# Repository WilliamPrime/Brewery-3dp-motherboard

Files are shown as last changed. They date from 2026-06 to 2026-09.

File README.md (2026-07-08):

# Brewery-3dp-motherboard
A 3d printer expansion board designed to help with monitoring and managing thermals in a 3d printer

# Key featurs

- supports 12-30V input
-20 buffered thermistor inputs
- 12 fan outputs each with selection between 5V,12V and Vbus
- 12V is dropped down with a buck converter on the board with 12A max
  - if the input voltage is 12V the 12V buck shouldnt be used
- 5V is dropped down with a buck converter on the board with 12A max

- 4 Pwmed outputs meant for heaters or really beefy fans
- 35A max per output, 62A max across all of the ports
  - the heaters are on a seperate fuse and terminal in, allowing you to save power budget for fans or just run things at a different voltage.

So you could you could use the thermistors to do something like 

- 12 for motors
  - would allow for checking in places where you suspect hotspots, but also coldspots.
  - would montior, Extruder, Z, and then 4 motor for an AWD gantry
- temp of outside of pannels
- ambient air temp
- electronics enclosure air temp
- lower printer air temp
- mid printer air temp
- upper printer air temp
- bed edge temp 
- frame temp

# KiCAD photos



# Firmware

This board uses an STM32F407ZGT6 MCU, which is supported by mainline klipper and marlin.

# BOM

| Part | Item cost | shipping+tax cost | Total cost for item(s) | Notes |
|---|---|---|---|---|
| LCSC components | $157.72 | $39.63 | $190.90 | ordering enough to populate the 5PCBs |
| JLC PCB + stencil | $92.09 | $48.06 | $140.15 | No PCBA, im handsoldering, the boards |
| | | | | |

Total cost $331.05

There is a detailed break down of the parts to be ordered on LCSC [**here**](https://github.com/WilliamPrime/Brewery-3dp-motherboard/blob/main/PROD/Brewery_Alpha_0.01_LCSC%20bom.csv)

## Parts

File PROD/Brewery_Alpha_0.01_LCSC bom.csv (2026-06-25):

Designator | Footprint | Quantity | Value | LCSC Part #
C10, C3, C52_2, C6, C7, C72, C73, C74, C75, C76, C77, C78, C79, C8, C80, C81, C82, C83, C84, C85, C86, C87, C9 | 603 | 23 | 4.7uF | C162274
C11, C12 | 1210 | 2 | 4.7uF | C650971
C13, C14 | 1206 | 2 | 470nF | C5448902
C15, C16, C26, C39, C44, C53, C54, C55, C56, C57, C58, C59, C60, C61, C66, C67, C68, C69, C70, C71 | 402 | 20 | 100nF | C17702730
C17, C45 | 402 | 2 | 1uF | C48986272
C18, C19 | 402 | 2 | 56nF | C48642889
C2, C22, C23, C4 | C_Radial_D6.3mm_H7.0mm_P2.50mm | 4 | 47uF | C42371892
C20, C21 | 1206 | 2 | 2.2uF | C170101
C24, C5 | 1210 | 2 | 10uF | C2178567
C27, C28 | 603 | 2 | 100nF | C149620
C29 | 603 | 1 | 6.8pF | C376800
C30 | 402 | 1 | 6.8pF | C880645
C31, C32 | 402 | 2 | 8.2nF | C49451355
C33, C34 | 402 | 2 | 1nF | C301925
C35 | 805 | 1 | 47uF | C386022
C40, C41 | 402 | 2 | 390pF | C49451349
C42, C43 | 1210 | 2 | 22uF | C2918488
C46, C47 | 603 | 2 | 2.2uF | C7432779
C52 | 603 | 1 | 4.7uF | C48579647
D1, D2, D21, D22, D23, D24, D25, D26, D27, D28, D29, D3, D30, D31, D32, D33, D34, D35, D36, D37, D38, D39, D4, D40, D41, D42, D43, D44, D45, D46, D47, D48, D49, D50, D51, D52 | D_SOD-323 | 36 | D55V0M1B2WS-7 | C20615816
F1, F4 | Untitled | 2 | Fuse | C5249802
F2, F3 | XF-509P | 2 | Fuse | C41371872
J11 | USB_C_Receptacle_Amphenol_124019772112A | 1 | USB_C_Receptacle_USB2.0_14P | C2927038
J2, J29, J3, J31, J33, J35, J37, J39, J4, J41, J43, J45, J47, J49, J5, J51, J52, J53, J54, J55, J56, J57, J58, J59, J60, J61, J62, J63, J64, J65, J66, J67 | JST_XH_B2B-XH-A_1x02_P2.50mm_Vertical | 32 | JST-XH | C3012114
J1,J16,J26, J27, J68, J69 | KF135T-10.16-2P | 6 | Screw_Terminal_01x02 | C475108
J28, J30, J32, J34, J36, J38, J40, J42, J44, J46, J48, J50 | PinHeader_2x03_P2.54mm_Vertical | 12 | jumpers | C42431837
J6 | PinHeader_1x03_P2.54mm_Vertical | 1 | Conn_01x03_Pin | C5383112
L1, L2, L4, L5 | IND_SRP1038A_BRN-M | 4 | 3.3uH | C3015512
L3 | 7x6.6mm-inductor-M | 1 | 2.2uH | C41415584
R1, R122, R123, R128, R129, R134, R135, R140, R141, R146, R147, R152, R153, R158, R159, R164, R165, R2, R29, R3, R4 | 1206 | 21 | 4.7k | C311962
R10, R124, R125, R126, R127, R130, R131, R132, R133, R136, R137, R138, R139, R142, R143, R144, R145, R148, R149, R15, R150, R151, R154, R155, R156, R157, R16, R160, R161, R162, R163, R166, R167, R168, R169, R17, R18, R7, R8, R9 | 402 | 40 | 1k | C54102207
R100, R102, R104, R106, R108, R110, R112, R114, R116, R118, R120, R98 | 603 | 12 | 2k | C217935
R101, R103, R105, R107, R109, R111, R113, R115, R117, R119, R121, R99 | 603 | 12 | 20k | C50397009
R11, R13 | 402 | 2 | 80.4k | C851509
R12, R14 | 402 | 2 | 8.45k | C728566
R19, R20 | 402 | 2 | 2.1ohm | C18164296
R21 | 402 | 1 | 5.76k | C49653870
R40 | 402 | 1 | 51k | C53109425
R41 | 402 | 1 | 22.1K | C852648
R42, R43 | 603 | 2 | 1.02k | C50670244
R44, R45 | 402 | 2 | 1.47k | C49654490
R46 | 402 | 1 | 1.5k | C281775
R47 | 402 | 1 | 3.4k | C852765
R5, R6 | 603 | 2 | 1ohm | C2575859
R52, R53 | 402 | 2 | 5.1k | C453708
R54 | 402 | 1 | 21k | C2998083
R55 | 402 | 1 | 18k | C49653933
R60, R61 | 402 | 2 | 130ohm | C49653526
R80, R84, R86, R88 | 402 | 5 | 2k | C54531046
R22, R23, R24, R25, R26, R27,R81, R85, R87, R89 | 402 | 11 | 20k | C55098299
R82, R83 | 603 | 2 | 43 | C3017767
R90, R91, R92, R93, R94 | Milliohm HoT-2-4.5-11-I | 5 | 0Ohm | C5357551
SW1, SW2 | CAX TS-1185-W-4P-H1.8-160 | 2 | SW_Push | C2909682
U1, U30, U31, U32, U33 | TSSOP-14_4.4x5mm_P0.65mm | 5 | MCP6004 | C42370557
U10, U16, U17, U18, U19, U20, U21, U22, U23, U24, U25, U26, U27, U28, U29, U34, U35, U7, U8, U9 | DOZ45N03T | 20 | DOZ45N03T | C49441964
U11 | SOT-23-6 | 1 | USBLC6-2SC6 | C7519
U14 | LQFP-144_20x20mm_P0.5mm | 1 | STM32F407Z_E-G_Tx | C19156
U2 | RJR0014A-MFG | 1 | LM61430AFSQRJRRQ1 | C3188037
U4, U5 | RGY0020B | 2 | LM25145RGYR | C2876740
AA | na | 12 | jumper jumpers | C5305

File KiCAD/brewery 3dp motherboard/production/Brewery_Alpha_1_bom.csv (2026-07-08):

Designator | Footprint | Quantity | Value | LCSC Part #
C10, C3, C6, C7, C72, C73, C74, C75, C76, C77, C78, C79, C8, C80, C81, C82, C83, C84, C85, C86, C87, C9 | 0603 | 22 | 4.7uF
C11, C12 | 1210 | 2 | 4.7uF
C13, C14 | 1206 | 2 | 470nF
C15, C16, C26, C39, C44, C53, C54, C55, C56, C57, C58, C59, C60, C61, C66, C67, C68, C69, C70, C71 | 0402 | 20 | 100nF
C17, C45 | 0402 | 2 | 1uF
C18, C19 | 0402 | 2 | 56nF
C2, C22, C23, C4 | C_Radial_D6.3mm_H7.0mm_P2.50mm | 4 | 47uF
C20, C21 | 1206 | 2 | 2.2uF
C24, C5 | 1210 | 2 | 10uF
C27, C28 | 0603 | 2 | 100nF
C29 | 0603 | 1 | 6.8pF
C30 | 0402 | 1 | 6.8pF
C31, C32 | 0402 | 2 | 8.2nF
C33, C34 | 0402 | 2 | 1nF
C35 | 0805 | 1 | 47uF
C40, C41 | 0402 | 2 | 390pF
C42, C43 | 1210 | 2 | 22uF
C46, C47 | 0805 | 2 | 2.2uF
C52 | 0805 | 1 | 4.7uF
D1, D2, D21, D22, D23, D24, D25, D26, D27, D28, D29, D3, D30, D31, D32, D33, D34, D35, D36, D37, D38, D39, D4, D40, D41, D42, D43, D44, D45, D46, D47, D48, D49, D50, D51, D52 | D_SOD-323 | 36 | D55V0M1B2WS-7
F1, F4 | Untitled | 2 | Fuse
F2, F3 | XF-509P | 2 | Fuse
J1 | KF135T-10.16-2P | 1 | power in
J11 | USB_C_Receptacle_Amphenol_124019772112A | 1 | USB_C_Receptacle_USB2.0_14P
J16 | KF135T-10.16-2P | 1 | heater in
J2, J29, J3, J31, J33, J35, J37, J39, J4, J41, J43, J45, J47, J49, J5, J51, J52, J53, J54, J55, J56, J57, J58, J59, J60, J61, J62, J63, J64, J65, J66, J67 | JST_XH_B2B-XH-A_1x02_P2.50mm_Vertical | 32 | JST-XH
J26, J27, J68, J69 | KF135T-10.16-2P | 4 | Screw_Terminal_01x02
J28, J30, J32, J34, J36, J38, J40, J42, J44, J46, J48, J50 | PinHeader_2x03_P2.54mm_Vertical | 12 | jumpers
J6 | PinHeader_1x03_P2.54mm_Vertical | 1 | Conn_01x03_Pin
L1, L2, L4, L5 | IND_SRP1038A_BRN-M | 4 | 3.3uH
L3 | 7x6.6mm-inductor-M | 1 | 2.2uH
R1, R122, R123, R128, R129, R134, R135, R140, R141, R146, R147, R152, R153, R158, R159, R164, R165, R2, R29, R3, R4 | 1206 | 21 | 4.7k
R10, R124, R125, R126, R127, R130, R131, R132, R133, R136, R137, R138, R139, R142, R143, R144, R145, R148, R149, R15, R150, R151, R154, R155, R156, R157, R16, R160, R161, R162, R163, R166, R167, R168, R169, R17, R18, R7, R8, R9 | 0402 | 40 | 1k
R100, R102, R104, R106, R108, R110, R112, R114, R116, R118, R120, R98 | 0603 | 12 | 2k
R101, R103, R105, R107, R109, R111, R113, R115, R117, R119, R121, R99 | 0603 | 12 | 20k
R11, R13 | 0402 | 2 | 80.4k
R12, R14 | 0402 | 2 | 8.45k
R19, R20 | 0402 | 2 | 2.1ohm
R21 | 0402 | 1 | 5.76k
R22, R23, R24, R25, R26, R27 | 0402 | 6 | 20k
R28, R30 | 1206 | 2 | 100
R40 | 0402 | 1 | 51k
R41 | 0402 | 1 | 22.1K
R42, R43 | 0603 | 2 | 1.02k
R44, R45 | 0402 | 2 | 1.47k
R46 | 0402 | 1 | 1.5k
R47 | 0402 | 1 | 3.4k
R5, R6 | 0603 | 2 | 1ohm
R52, R53 | 0402 | 2 | 5.1k
R54 | 0402 | 1 | 21k
R55 | 0402 | 1 | 18k
R60, R61 | 0402 | 2 | 130ohm
R80, R84, R86, R88 | 0402 | 4 | 100
R81, R85, R87, R89 | 0402 | 4 | 10k
R82, R83 | 0603 | 2 | 22
R90, R91, R92, R93, R94 | Milliohm HoT-2-4.5-11-I | 5 | 0Ohm
SW1, SW2 | CAX TS-1185-W-4P-H1.8-160 | 2 | SW_Push
U1, U30, U31, U32, U33 | TSSOP-14_4.4x5mm_P0.65mm | 5 | MCP6004
U10, U16, U17, U18, U19, U20, U21, U22, U23, U24, U25, U26, U27, U28, U29, U34, U35, U7, U8, U9 | DOZ45N03T | 20 | DOZ45N03T
U11 | SOT-23-6 | 1 | USBLC6-2SC6
U14 | LQFP-144_20x20mm_P0.5mm | 1 | STM32F407Z_E-G_Tx
U2 | RJR0014A-MFG | 1 | LM61430AFSQRJRRQ1
U4, U5 | RGY0020B | 2 | LM25145RGYR

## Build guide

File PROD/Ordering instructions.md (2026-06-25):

Hi, for some reason youve decided you want to order the stuff before ive tested it.

Bold.

But anyway, the PCB has been designed for the outer layers to be at least 2Oz copper, and the innner layers at least 1Oz.

Other than that, its just a 100x140mm 4 layer PCB, nothing special, should fit into basic tolerances.

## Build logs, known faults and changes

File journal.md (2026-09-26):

# Day 1 07/06/2026 1.5 hours

## So im starting this project
My first experience with modifying a klipper board was moddifying the [klipper expander by timmit99](https://github.com/timmit99/Klipper-Expander), to have bigger mosfets as I wanted to attach some chunkier fans that wanted over 4A.

which turned it from 
this


to this


Same mounting holes, mostly the same circuitry, just bigger mosfets and a type C connector instead of a micro b port.

## time to set out what i want from this

- at LEAST 20 thermistor inputs
- all thermistor input to have overvoltage protection, i dont want to accidentally kill anything with static as i dont know where users will be sticking them
- 12 fan ports with 1-2.5A 
  - all of these fan ports should have a selector to pick between 5v, 12v or 24v/Vbus
- 4 fan parts with ~5A of max current
- USB c in with ESD protection/isolation

I should probably also make a checklist of what i need to get done

- [ ] pick an MCU
- [ ] sort out OVP for the thermistors
- [ ] sort out OCP for the fans
- [ ] sort out how im doing to do selectable voltage for the fans
- [ ] pick mosfets for the fans
- [ ] bom optimisation

## picking an MCU IC
I probably want some sort of STM32 since the klipper support for those is really good,
Time to hunt in the [ST mcu portfolio](https://www.st.com/content/st_com/en/stm32-mcu-developer-zone/mcu-portfolio.html) for something that looks good.

Ive stopped hunting in ST's tool and now im hunting in LCSC, if im buying the part from LCSC, then its useful to check it there so i dont go to find it there and be dissapointed it not there yet. 

Andddd i thought id found chip that was vuagely in the right direction, and realised another constraint i needed to look out for, does klipper support the MCU ? I know i could theoretically try and implament klipper support for a random STM32 chip however i feel like that might be difficult and i dont even know where i would start, so i will leave that as a future me project!

Anyway i found the list of currently supported MCUs for klipper, yipeeeeeee!


The first MCU I picked wasnt on LCSC
The second one didnt have klipper support

My third MCU seems to be suitable, the [STM32F07ZGT6](https://www.lcsc.com/product-detail/C19156.html)

It features:
- an ARM Cortex-M4 cpu core running at 168MHz
- 82 I/Os
- an LQFP-100(14x14) package so i can actually solder it by hand
- 512KB of built in programme storage so i can have klipper on it
- usb 2.0 support
- a built in oscilator
- has klipper support

checking the data sheet, the variant i picked has 24ADC channels which surpasses the minimum number of thermistors i want.


I could pick a smaller, cheaper STM32 and then use a number of ADS1115 4 channel ADCs via I2C, as [klipper supports those](https://www.klipper3d.org/Config_Reference.html#ads1x1x), however that might add a chunk  of mess to the config, and at ~$2 per IC, its a lot more expensive per thermistor than just buying a bigger STM32

The size (20mm x 20mm) is a tad annoying, but it is what it is, im not sure how else i expect to get so many IO/s in an LQFP package without it being big, only way to make it smaller would be BGA or similar, which i dont feel like dealing with.

So currently it looks like 
- [x] pick an MCU
- [ ] sort out OVP for the thermistors
- [ ] sort out OCP for the fans
- [ ] sort out how im doing to do selectable voltage for the fans
- [ ] pick mosfets for the fans
- [ ] start on the schematic
- [ ] bom optimisation
Onto the next part! I suspect this might be a tad tricky and involve me learning a chunk of new things

spent some time learning about op amps as i kept spotting them in some thermistor circuits.

# Day 2 08/06/2026 5.7 hours

## sort out OVP for the thermistors

First solution ive found is maybe using a TSV diode to protect them, however Im not sure how well that would do, and leakage current could be a BIG issue

Ive spotted is that some other designs use OP amps to buffer their inputs , if an op amp can help reduce reading errors, im all for it.

the OPA320, OPA323 and OPA2320 


If the OPA2320 , is a dual channel version of the OPA320, why is the OPA2320 arround 25% cheaper than the OPA320? Is there something im missing? Im aware of pricing this whole time because if i need to add 20channels worth of something price is going to be important.

Im also just going through all of the ADC temperature sensors klipper supports incase one of them is a value gem compared to an STM32.
No gems, everything was quite pricey.

Anyway back to hunting for op apms and knowledge of how to implament them with OVP

Another op amp im looking at is the MCP6004 and that series

## starting on the schematic

I wanted a break from the op amp stuff, time to do something im a bit more comfortable with, schematics!



now im curious if i could do the thermistor op am circuits as a heirarchical sheet to make it a bit less messy, anyway

It also looks like the LQFP144 package i picked can pull a good ammount of power





I will probably use a pair of ideal diodes circuits to the OR the usb 5V and 12-24V input for heaters for the drop down for the STM32.
That allows to have power via USB for flashing, but also means i can have most of the power comming from the 24V PSU not the USB bus.

Nope ive decided against that, i will just add a jumper to pick between them, i dont feel like adding $2-4 of components.

trying to pick resistors for the voltage divider is suprisingly tricky


Anddd there we go high efficiency 3.3v reg, that took a while


I also found another project with similar goals 
that being [prunt3d](https://prunt3d.com/), they used an ESD diode that appears wayy smaller than the one i was going to use ,which is nice, so ill use the [D55V0M1B2WS-7](https://www.lcsc.com/product-detail/C1976275.html) instead of the [ST SMBJ48A-TR](https://www.lcsc.com/product-detail/C133659.html) i was going to use

I did a little bit more work on the 3.3V reg, I may have forgotten a cap, however I added it back in so its fine.
Ive also been picking parts for some things as I go and adding them into my cart in LCSC


Currently the schematic looks like this 

currently the checklist looks like this, same ammount of things need doing, but ive still made good progress on the supporting components.
- [x] pick an MCU
- [ ] sort out OVP for the thermistors
- [ ] sort out OCP for the fans
- [ ] sort out how im doing to do selectable voltage for the fans
- [ ] pick mosfets for the fans
- [ ] start on the schematic
- [ ] bom optimisation

## Selectable voltage for the fans

For some reason i kind of feel like doing more volage regulator stuff

, if I want 5V and 12V options for fans, I probably need to drop down the 24V to that

# Day 3 09/06/2026  3.05 hours

Im still working on the selectable fan votlage
still working on putting together a pair of buck converters so I can have a 5V and a 12V rail without needing the user to use external power supplies.



Im not using the mosfet recommened by TI since its really expensive, I found an alternative thats substantially cheaper, i do need to make my own footprint which is normally ok,
but this is REALLYY confusing me


In the end i just used coordinates to align everything


Since i picked an IC thats super versatile
my 5v converter looks like this

and my 12v like this


All that changes is two resistors comming out of FB that determine the voltage output.

Im getting reallyy confused how to get mosfets to do what i want 



I was going to have a 3 switch, dip switch ,and then use that to let the use select between 5, 12, and 24v.
and then have each switch control a mosfet

Ignore how awfully messy this is


for the 5v rail it works

but then after that

the 12v or 24v rails will start backfeeding the 5v, and causing the source to be at 12v or 24v, which is higher than the drain at 5v, so current flows

I dont know how to fix this as I have no clue what i need to do to fix it.
So i need to watch youtube video or find some way to learn about them that dont just confuse me 

# 11/06/2026 7.3 hours

## getting on with it, addressing scope creep that happened before the project started
First thing i went and did was look at overcurrent protection for the fan ports, since i have so many, it would add AT LEAST $12 IC cost alone ignoring all the extra passives.
It would also add a bunch of complexity, so i dont need it, bye bye fan  OCP, long live the 12A or 30A fuse protecting the input terminals!

originally i wanted to do the voltage switching via dip switches, jumpers can just be kind of annoying, however i couldnt figure out how to set up an ideal switch model thingy with mosfets, so there would have been all sort of backcurrent issues. So i will do it the way that ive seen other boards do it, with jumpers. Im not the biggest fan of the jumper method since at high currents im semi worried about melting things, but I guess its "fine", its still a nice feature.
How many people use their JST-XH ports at 3A anyway?

Here is one of MANY attempts to get something to work in [Faldstad](https://www.falstad.com/circuit/), they often would have weird issues like the output volage being lower than I expected, with the cause of the voltage drop really not being clear. 


Still staying on the theme of fans, I need to pick mosfets for them, I think i will use the same mosfets that i used for the buck converters, massively overspecced , I DO NOT need 45A at 30V, however they are compact and cheap at ~$0.089 per mosfet,so still a perfectly reasonable choice . Yipeee ive avoided adding another part to the BOM.

So an indiviual fan circuit looks like this,


And 12 of them like this.


I chose to rename the FanH to Heaters1-3, it just felt correct give the power the mosfets are capable off. As the mosfets are capable of 45A, there will be a fuse rated at ~30A to protect the board and terminals.


Ive also ditched overcurrent protection for the thermistors, I have added ESD protection in the form of an ESD diode, and some resistors to hopefully stop reduce how nasty any ESD getting to the op amp is.

I picked the MCP6004 as the op amp for this board, its compact , low power, cheap, and more than good enough for this application.

Thats all the thermistor stuff done!


I did also shuffle arround all of the pins the thermistors were connected to because I forgot to check the pins had an ADC attached to them.


which means our list of things to do now looks like this
- [x] pick an MCU
- [x] thermistor op amps
- [x] sort out how im doing to do selectable voltage for the fans
- [x] pick mosfets for the fans
- [x] start on the schematic
- [ ] finish off schematics
- [ ] tidy up schematics
- [ ] bom optimisation
- [ ] routing

And the overall schematic now looks like this

the "tidy up schematics" box probably makes more sense now...

# 22/06/2026 AHHH THE ROUTINGGG AND OTHER STUFF 30 hours

So Ive done a lot of stuff since the last journal , but a LOT of it was the same sort of stuff

A LOT reading data sheets like [this one 
](https://www.ti.com/lit/ds/symlink/lm25145.pdf?ts=1782024874461)
I had particular "fun" with that one trying to make sure i followed as much of the layout guideance as possible!


I had to follow the layout guide because i was doing the layout,
because i finished off virtuially all of the schematic!

Currently the board looks something like this



A lot of the routing and layout was done in smaller discrete chunks and then smooshed into the bits of the PCB layout that were allready decided, im not sure if it was the right approach.
That approach caused me to do a lot of 
- laying out and routing a block
- moving the block into place
- moving arround parts in the block to make it fit better
- moving the block into a second better place
- more moving arround parts in the block to make it fill gaps and fit better

which felt pretty inefficient, but on the other hand I dont think the whole board could have been routed at once given the shear ammount of components and design guidelines imposed

One of the big decisions I was toying with was if i should split the PCB into two PCBs.
- a pcb for the high power stuff
- a pcb for the MCU, USB in, Fan ports 

I know if I make it all one board it will be over 100x100mm which will make it far more expensive from someone like JLC PCB
If i make it two boards then I need to deal with joining them together with some sort of connector.

Ultimatly i decided to go against the split board idea simply because i didnt want to add any extra complexity.

The PCBs wont be the cheapest though since i need 2Oz surface copper weight because of the high currents.
They also look like they will be arround 100x130mm
So i recon it will be arround $80 for 5PCBs

The buck converters did take up a good 4-6 hours, I kept realising there was another thing i could do to better optimise the footprint or adhesion to the guidline

This was the first revisision


But when you have multiple of those, the shape makes fitting them in quite akward, so i moved arround the caps to make it squarer


But that still results in dead space, so i wiggled arround some passives to try and gain more room

And that worked pretty well!!!

which means our list of things to do now looks like this
- [x] pick an MCU
- [x] thermistor op amps
- [x] sort out how im doing to do selectable voltage for the fans
- [x] pick mosfets for the fans
- [x] start on the schematic
- [ ] finish off schematics
- [X] tidy up schematics
- [ ] bom optimisation
- [ ] routing

Still some routing left, 
There will be BOM optimisation to do as i keep changing 0402 to 0602s for the sake of being able to run traces under them and also sanity when soldering.
If i want a couple of neopixel ports then i will need to add them to the schematic properly

I should also add 
- [ ] A diagram with a proper diagram of the pinout
but that should wait for after ive finished the layout as current im still playing arround with how to organise things.

# 22/06/2026 the last bit of routing is proving to be a bit of a pain 5 hours


trying to route everything is just becomeing more and more of a pain because the traces often connect to the wrong side and in a place that just doesnt make sense.

I recon the soluation to this is abandoing a pin numbering scheme that makes sense, making a list of all pins with ADC and just picking ones that minimise the ammount of crossing over i need.
The crossing over is really annoying as the vias just prove to be in the way again and again.

PA0-7
PB0, PB1
PC0-5
PF3-10

are the 24 GPIO pins i can use to get an ADC connection.

Given there are 24 and I need to use 20 of them, I dont think its going to give me a ton of flexibility to stop traces needing to travel to the bottom of the chip instead of the top, but knowing which i can play with should still help in avoiding some of the crossing over.

Ive chucked a blue box next to each pin i can juggle arorund.


I will also probably do the same for the PWM outputs


I ended up getting a list of all the pins, and a list of which pins have an ADC in, and which have a PWM out.
Then taking away the ADC in from the PWM out so i dont accidentally use a pin i want.

I also removed pins where the TIM channel was used by multiple pins, leaving me with that selection of boxes

The part i have routed are much neater, there are still all of the fan PWM inputs to route, so its too early to say how its truely turned out.

I would also throw in a bit of DCR here and there to make DRC more bareable at the end.
It may be a lot of errors, but it was a lot higher :sob: 


Anyway, still lots more routing to do! 

# finishing off the PCB 23/06/2026 -6 hours

This session has been a lot of cleaning things up, such as the routing for everything connecting to the MCU

previously it looked like this
image (5)
That mess was only going to get worse, I hadnt even get routed half of the fans or any of the heaters.

With everything routed to the MCU it looks like
image (6)
which I think is a LOT cleaner

I also spent a while trying to work my way through all of the DRC issues

that is the highest number of DRC errors ive ever seen.

Some of the issues were harder to sovle and ive still not solved them, just ignored them as I think there is a good chance that its just KiCAD glitching out

such as this scenario
image (8)
image (7)
image (9)

the anular for that hole should be 0.125mm , but kicad thinks its 0.0999999 no matter what i change the diameter to.
I needed to change the anual to something larger so whatever PCB fab i pick can make it, and that still didnt fix it.
If my PCB fab can do it, then im happy, kicad can go sulk about it some more or something.

Anyway there were a LOT of DRC issues, it took a while.

My next step is going to be trying to make a bom file with all of LCSC part numbers.

#24/06/2026 AHHHH - arround 4-6 hours

most of this chunkkk of time has been spent picking components on LCSC

The bom starts out looking like that, and then I needed to find the component in the circuit and check for any special requirements

For example with the resistors used as a voltage divider for the thermistors i wanted them to be fairly accurate. 
But for some other things like where the resistors were simply there for the purpose of limmitting current I would quite happily pick +-10% if it existed and was cheaper

The caps were a bit tricker, as for some of them , picking a higher voltage rating would make them a lot pricier
for example the 1210 footprint 4.7uF caps needed for the 3.3V voltage regulator,
If you want then in 5V , they cost arround $0.05 each, but if they are exposed to the incomming 24-30V , they need to be rated to something higher like 36V
which then makes them cost $0.23 each

picking the voltage rarting for a cap was also interesting in situations like when the cap is used in a bunch of places, when it was a negligable ammount more i would go for 36V rated caps as that would be fine no matter the voltage input

There was also a bunch of noticing stuff like "uh oh, why is that 0402 cap 10uF" and then proceeding to realised that needs to be bigger to actaully have that much capacitance

or when i realised that the reistors i used to limmit the inrush current into the mosfet gates werent enough, it would cause an inrush higher than what the MCU GPIO pins were rated for.
Which once again led downa rabbit hole of changing out components, re creating the BOM and copying over the stuff that was allready done.

There were also some really annopying things i encountered, such as the voltage regulator i used for 3.3V and my chosen MCU both being out of stock on LCSC.
After some research on LCSC i found an automotive variant of the vreg that was a little more, but a pin for pin replacement.

The MCU was a bit trickier, but ultimatly i found a version with a higher temp rating , other than it was identical to the original MCU.
Well, the price was also more, but changing the MCU would require a chunk more work and re routing, and its not like I chose an MCU that is EOL, so the project should still be recreatable in the future.

That IC bom from the start now looks like this

An LCSC part num next to every component.

# Start of the build!!!

you will probably notice that the build was uploaded all in one go, thats because when I was assembling the PCB I would have my laptop next to me for KiCad etc, and as wonderful as github is, loosing your progress because you accidentally close the chrome tab before you commit the changes to the .md is reallyyyy annoying , so I journalled everything into Obsidian notes, and then copy pasted to here!

# 06/07/2026 PART ARRIVING!!! 0.5 hours

wow the terminals are big, today was spent sorting the components into piles ready for as soon as the PCBs arrive!

if you're wondering what piles i sort them into
- resistors
	- by value footprint, 
	- if multiple of same value, smallest package first
- capacitors
	- by value footprint, 
	- if multiple of same value, smallest package first
- special SMD stuff
	- stuff like op amps, micro conctrollers, mosfets etc
- through hole stuff



# 08/07/2026 PCBs ARRIVED TIME TO SOLDER!!! - 4h




I got a decent stencil application, but i think  i accidentally went over the same area twice on the right hand side of the board, so there was a lot of paste there



also made a good start onto placing components!!!



oh., and i regret using 0402, i can do it, its just that 0603 is soo muchhh easier, i can do 0603 with my fingers, 0402 and 0201 are just ,needlessly fiddly for a board like this.

# 09/07/2026 still placing new parts on - 3h
so, it says this is a new day in the journal, but urm, its past midnight!!!
since i don't want all the flux in the paste to dry up and make my life harder, I kept placing components!!
and wow there are a lot of components!



i dont know why i didnt get a photo before i reflowed
but here is a photo post reflow of me trying to cool the board!!



once your usb wires start looking like this, you know the project is going to get more intersting.



so it turned out that i picked the wrong type of USB-C connector footprint in KiCad, which made for an interesting discovery when trying to solder on the USB C port...

# 10/07/2026 USB + trying to get power on the 3v3 rail - 7 hours

I finished bodging the USB thing, so that should be sorted, not great, but okay.



have been trying to identify why im not getting 3.3v



photos of the area don't make it look awful 

ive got a janky thing instead of the jumper, i dont want to solder the through hole pins for the selection source for the 3.3v reg, as otherwise i wont get as good contact with the hotplate when reflowing, so ive done this


i still need to remove it, but its not as hard

5v looks clean ish, but im not sure whats causing that nose



and then my 3.3v rail is looking like this



its supposed to be operating at around 2.2MHz so i dont expect anything spicy at this scale, but given im at 1.12V im guessing ive either got a mistake on my resitsors, or the freq selection stuff.



and now im just getting noise

noise that keeps changing


anddd i worked out i left a pin floating that should have been grounded...



so now that's bodged with a wire under it that i can join to gnd somewhere

so much time spent trying to work out exactly whats gone wrong :sob: 

# 11/07/2026 more trying to fix the 3.3V regulator - 6 hours

I've really been having an experience trying to fix the 3.3V reg, I think the long wire i tried to use before was too long and acting as an atenna at those frequencies or just something was wrong.
Soooo here are my various attempts including
- shorter wire
- shorter wire again
- scrapping of coppuer under the footprint to try and get a bridge between the pin and the copper
- another attempt at that
- even more attempts at that
_DSC5476
_DSC5472
_DSC5475
_DSC5468
_DSC5465
_DSC5449

the 3.3V reg still doesn't work...

# 22/09/2026 soldering up another board - 3 hours 

Given how much reflowing I did on the original almost fully populated PCB, I thought to give myself the best chance of not just having random dead ICs, I should assemble a board where Ipopulate near the minimum components to test if it works properly.

_DSC6055



# 23/09/2026  placing the last parts onto the 2nd board and reflowing - 3 hours

i finally got all the parts onto the second board and reflowed all of it. Annoyingly since i waited so long the flux in the past dried out making the sticking of components down to the PCB much harder.



its not as clean as the other


but took less time to get populated as I skipped a bunch of stuff, and stuff that was harder to solder like the big inductors that sucked to get soldered.
# 24/09/2026 stm32 shaped 2.5W heater - 8 hours

today has been full of "experiences" when trying to get the PCB working

first thing i did that messed me up was soldering on a terminal 90degrees out of alignment...

Getting them to solder down was INCREDIBLY difficult , and getting one out was even harder,
When you have tons of vias, massive uninterrupted power planes, and extra thermal mass and conductivity from having of 2oz external copper, and 1oz internal copper , it make the experience even more "fun". I think it took a good 4min of dual wielding a hot air gun and a soldering iron to get it out. And "getting it out" meant getting it to drop around 2mm, so i could use side cutter to get it out because it did NOT want to come out.

here is a photo of the poor state that PCB was in :(



But in the end i got it out!!!

here is a photo of how the PCB looks now



which got me back to having a populated PCB!!

#### This is the part of todays journal where I explain the title being "stm32 shaped 2.5W heater"

So at this point I have
- a virtually fully populated PCB with a potentially heat damaged STM32
- a functionally populated board that shouldn't have any heat damaged components

So I get some things together


- multi meter because the owon P4305 has an amperage accuracy of arround +-10ma, if a healthy STM32 pulls 5-10mA, and a dead one pulls 0mA, then i cant tell the difference without the multimeter
- modern linear PSU that i trust to actually output the right voltage
	- using this for the 3.3V since ive had so many issues with it and its killed so much of my time
- 2nd PSU to do the 12-24V input

I hook everything up as you'd expect to the semi populated board as i thought id have a better chance getting something out of that one. I turn on the 3.3V psu and instantly hit the overcurrent protection, what on earth is pulling 1.5A of 3.3V?

So I grab a multimeter and measure the resistance between GND and the 3.3V rail, ~1Ohm, not normal

some extra attentive checking for shorted pads on the stm32 later and nothing looks wrong, but ive touched some pads up 
_DSC6074
_DSC6077
_DSC6076
_DSC6075

Try 2 , ***beeeep***, overcurrent protection again...
but nothing is catching fire, nothing is going bang etc, so given its a semi populated PCB, i thought id turn the overcurrent protection off, and just run up the current limit until i could feel a component getting warm. 

100mA, nothing,
200mA nothing, 
1.5A limit, YUP THE STM32 IS GETTING WARM FAST

The heat was coming from the package so i presume id probably managed to damage it with heat.

It being the fault of the STM32 was confirmed when i desoldered it an my GND-3.3V resistance dropped to 5.6kOhms

a replacement STM32 got that current down from 1.5A to ~7mA, which makes sense 

Pasted image 20260926011845

The board I thought would have issues only pulled ~5mA also in the healthy range, so hopefully i should have two boards that just need a flash then should work!

# 25/09/2026 actually getting it working and getting a demo video - 3 hours

well this makes for some fun trouble shooting


Pulls the right amount of power as if its a working stm32, but doesn't want to talk to me


Also a fun time to realize that breaking out the SWD pins is normally something that people do to help with troubleshooting.

its also certainly a setup im working with


So now i could have any of the following issues:
- issue with my pcb design (unlikely)
- issue with my USB cable "solution" (likely)
- issue with my power supply (unlikely)
- something else ??

Anddddd its communicating!!!

it fell into the  "issue with my pcb design", not as unlikely as I thought
Boot0 was properly set up with a pull down resistor and a switch to pull it up
But Boot1 was left floating, it should have been pulled down...
It was NOT broken out
soldering on the STM32s legs is trickyyyyy...



fan go spinny spinny  
*insert happy William noises*

# lessons ive learnt from this
- DOUBLE CHECK YOUR FOOTPRINTS
- THERMAL RELIFS ARE IMPORTANT TO MAKE THINGS SOLDERABLE WHEN YOUR PCB HAS 2OZ COPPER
- add holes so I can use a stand to hold the PCB
- make sure to break out the SWD pins an STM32, makes debugging easier
- be suspicious of stuff that is left floating in your schematic

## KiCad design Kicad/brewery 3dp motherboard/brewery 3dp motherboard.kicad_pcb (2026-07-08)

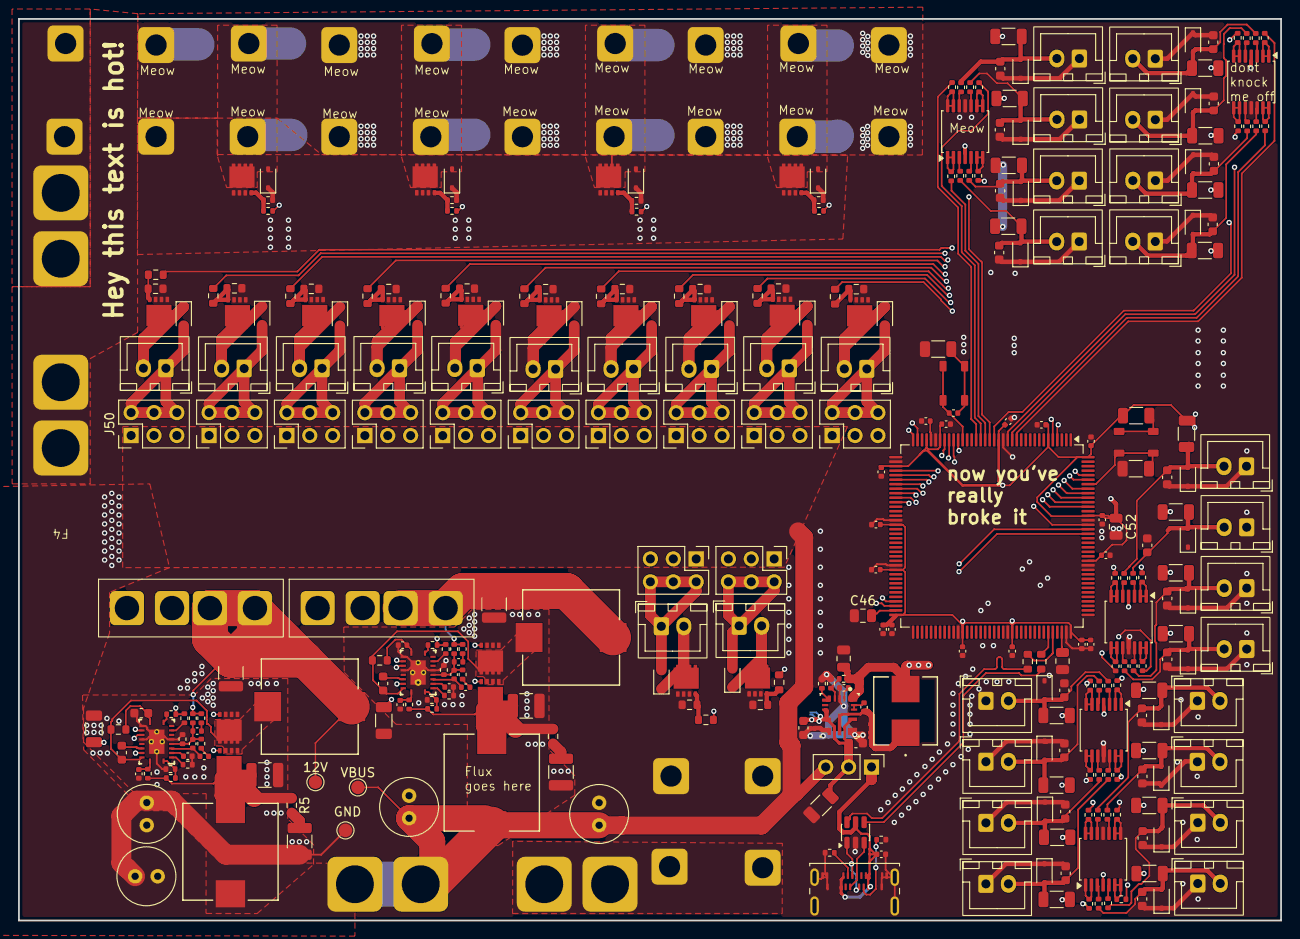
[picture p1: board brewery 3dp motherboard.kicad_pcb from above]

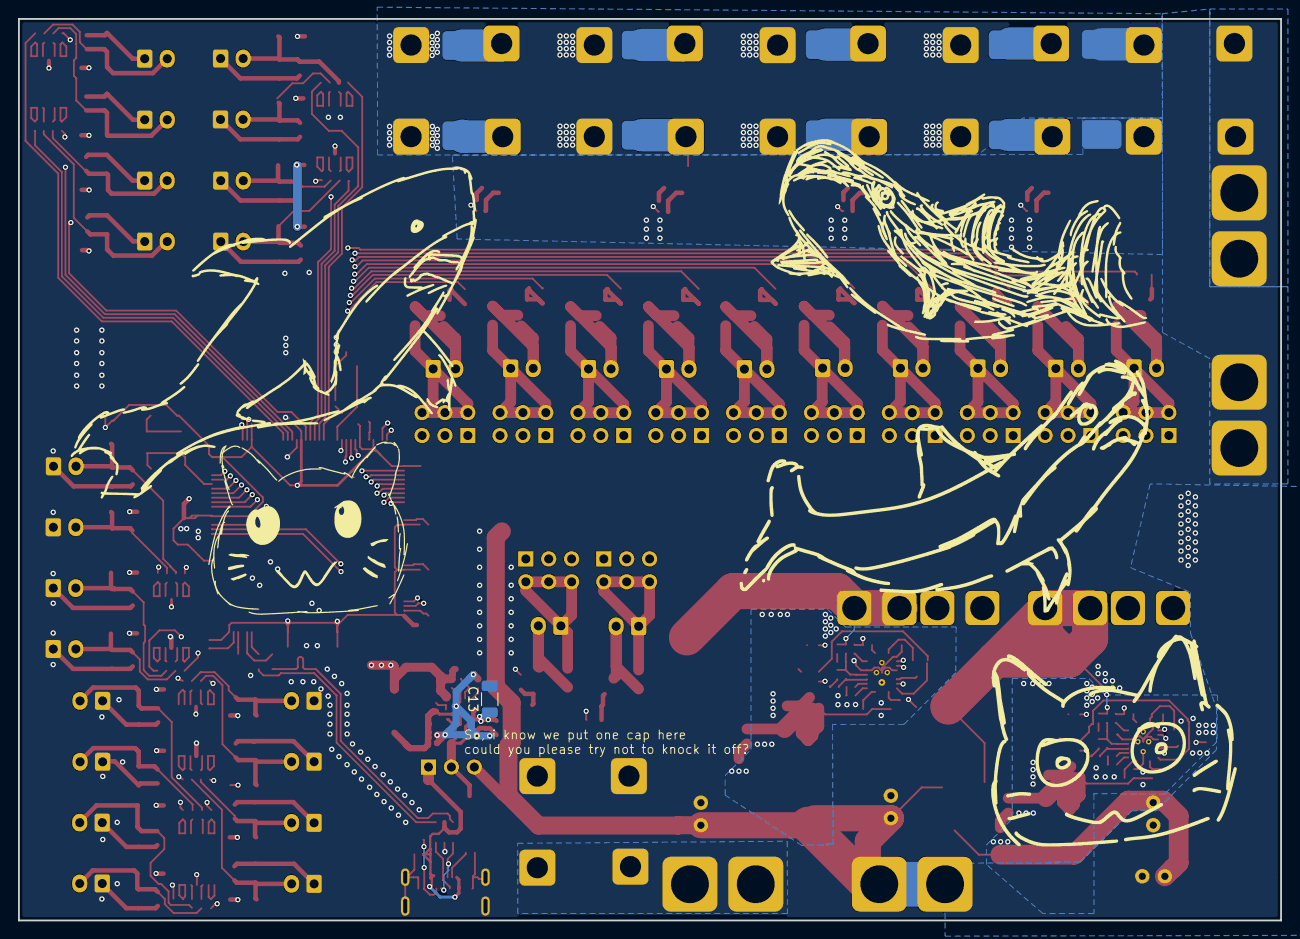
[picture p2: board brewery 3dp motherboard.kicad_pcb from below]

Board: 4 copper layers, 140.0 x 100.0 mm, 337 parts (6 on the bottom side), 208 nets.

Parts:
12V: TestPoint_Pad_D1.5mm
C2, C4, C22, C23: 47uF; C_Radial_D6.3mm_H7.0mm_P2.50mm
C3, C6, C7, C8, C9, C10, C72, C73, C74, C75, C76, C77, C78, C79, C80, C81, C82, C83, C84, C85, C86, C87: 4.7uF; C_0603_1608Metric
C5, C24: 10uF; C_1210_3225Metric
C11, C12: 4.7uF; C_1210_3225Metric
C13, C14: 470nF; C_1206_3216Metric
C15, C16, C26, C39, C44, C53, C54, C55, C56, C57, C58, C59, C60, C61, C66, C67, C68, C69, C70, C71: 100nF; C_0402_1005Metric
C17, C45: 1uF; C_0402_1005Metric
C18, C19: 56nF; C_0402_1005Metric
C20, C21: 2.2uF; C_1206_3216Metric
C27, C28: 100nF; C_0603_1608Metric
C29: 6.8pF; C_0603_1608Metric
C30: 6.8pF; C_0402_1005Metric
C31, C32: 8.2nF; C_0402_1005Metric
C33, C34: 1nF; C_0402_1005Metric
C35: 47uF; C_0805_2012Metric
C40, C41: 390pF; C_0402_1005Metric
C42, C43: 22uF; C_1210_3225Metric
C46, C47: 2.2uF; C_0805_2012Metric
C52: 4.7uF; C_0805_2012Metric
D1, D2, D3, D4, D21, D22, D23, D24, D25, D26, D27, D28, D29, D30, D31, D32, D33, D34, D35, D36, D37, D38, D39, D40, D41, D42, D43, D44, D45, D46, D47, D48, D49, D50, D51, D52: D55V0M1B2WS-7; D_SOD-323
F1, F4: Fuse; Untitled
F2, F3: Fuse; XF-509P
GND: TestPoint_Pad_D1.5mm
J1: power in; KF135T-10.16-2P
J2, J3, J4, J5, J29, J31, J33, J35, J37, J39, J41, J43, J45, J47, J49, J51, J52, J53, J54, J55, J56, J57, J58, J59, J60, J61, J62, J63, J64, J65, J66, J67: JST-XH; JST_XH_B2B-XH-A_1x02_P2.50mm_Vertical
J6: Conn_01x03_Pin; PinHeader_1x03_P2.54mm_Vertical
J11: USB_C_Receptacle_USB2.0_14P; USB_C_Receptacle_Amphenol_124019772112A
J16: heater in; KF135T-10.16-2P
J26, J27, J68, J69: Screw_Terminal_01x02; KF135T-10.16-2P
J28, J30, J32, J34, J36, J38, J40, J42, J44, J46, J48, J50: jumpers; PinHeader_2x03_P2.54mm_Vertical
L1, L2, L4, L5: 3.3uH; IND_SRP1038A_BRN-M
L3: 2.2uH; 7x6.6mm-inductor-M
R1, R2, R3, R4, R29, R122, R123, R128, R129, R134, R135, R140, R141, R146, R147, R152, R153, R158, R159, R164, R165: 4.7k; R_1206_3216Metric
R5, R6: 1ohm; R_0603_1608Metric
R7, R8, R9, R10, R15, R16, R17, R18, R124, R125, R126, R127, R130, R131, R132, R133, R136, R137, R138, R139, R142, R143, R144, R145, R148, R149, R150, R151, R154, R155, R156, R157, R160, R161, R162, R163, R166, R167, R168, R169: 1k; R_0402_1005Metric
R11, R13: 80.4k; R_0402_1005Metric
R12, R14: 8.45k; R_0402_1005Metric
R19, R20: 2.1ohm; R_0402_1005Metric
R21: 5.76k; R_0402_1005Metric
R22, R23, R24, R25, R26, R27: 20k; R_0402_1005Metric
R28, R30: 100; R_1206_3216Metric
R40: 51k; R_0402_1005Metric
R41: 22.1K; R_0402_1005Metric
R42, R43: 1.02k; R_0603_1608Metric
R44, R45: 1.47k; R_0402_1005Metric
R46: 1.5k; R_0402_1005Metric
R47: 3.4k; R_0402_1005Metric
R52, R53: 5.1k; R_0402_1005Metric
R54: 21k; R_0402_1005Metric
R55: 18k; R_0402_1005Metric
R60, R61: 130ohm; R_0402_1005Metric
R80, R84, R86, R88: 100; R_0402_1005Metric
R81, R85, R87, R89: 10k; R_0402_1005Metric
R82, R83: 22; R_0603_1608Metric
R90, R91, R92, R93, R94: 0Ohm; Milliohm HoT-2-4.5-11-I
R98, R100, R102, R104, R106, R108, R110, R112, R114, R116, R118, R120: 2k; R_0603_1608Metric
R99, R101, R103, R105, R107, R109, R111, R113, R115, R117, R119, R121: 20k; R_0603_1608Metric
SW1, SW2: SW_Push; CAX TS-1185-W-4P-H1.8-160
U1, U30, U31, U32, U33: MCP6004; TSSOP-14_4.4x5mm_P0.65mm
U2: LM61430AFSQRJRRQ1; RJR0014A-MFG
U4, U5: LM25145RGYR; RGY0020B
U7, U8, U9, U10, U16, U17, U18, U19, U20, U21, U22, U23, U24, U25, U26, U27, U28, U29, U34, U35: DOZ45N03T
U11: USBLC6-2SC6; SOT-23-6
U14: STM32F407Z_E-G_Tx; LQFP-144_20x20mm_P0.5mm
VBUS: TestPoint_Pad_D1.5mm

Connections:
+3.3V: C35.1, C52.1, C53.1, C54.1, C55.1, C56.1, C57.1, C58.1, C59.1, C60.1, C61.1, C66.1, C67.1, C68.1, C69.1, C70.1, C71.1, L3.2, R1.2, R2.2, R3.2, R4.2, R28.1, R40.2, R122.2, R123.2, R128.2, R129.2, R134.2, R135.2, R140.2, R141.2, R146.2, R147.2, R152.2, R153.2, R158.2, R159.2, R164.2, R165.2, U1.4 (V+), U2.1 (BIAS), U14.6 (VBAT), U14.17 (VDD), U14.30 (VDD), U14.33 (VDDA), U14.39 (VDD), U14.52 (VDD), U14.62 (VDD), U14.72 (VDD), U14.84 (VDD), U14.95 (VDD), U14.108 (VDD), U14.121 (VDD), U14.131 (VDD), U14.144 (VDD), U30.4 (V+), U31.4 (V+), U32.4 (V+), U33.4 (V+)
+5V: F3.1, J28.5, J30.5, J32.5, J34.5, J36.5, J38.5, J40.5, J42.5, J44.5, J46.5, J48.5, J50.5
+12V: F2.1, J28.3, J30.3, J32.3, J34.3, J36.3, J38.3, J40.3, J42.3, J44.3, J46.3, J48.3, J50.3
BOOT0: R29.2, SW2.2, U14.138 (BOOT0)
Fan1: R98.1, U14.127 (PG12)
Fan2: R106.1, U14.128 (PG13)
Fan3: R100.1, U14.129 (PG14)
Fan4: R108.1, U14.133 (PB3)
Fan5: R102.1, U14.134 (PB4)
Fan6: R110.1, U14.135 (PB5)
Fan7: R104.1, U14.136 (PB6)
Fan8: R112.1, U14.137 (PB7)
Fan9: R114.1, U14.139 (PB8)
Fan10: R118.1, U14.140 (PB9)
Fan11: R116.1, U14.5 (PE6)
Fan12: R120.1, U14.4 (PE5)
GND: C2.2, C3.2, C4.2, C5.2, C6.2, C7.2, C8.2, C9.2, C10.2, C11.2, C12.2, C13.2, C14.2, C15.2, C16.2, C17.2, C18.2, C19.2, C20.2, C21.2, C22.2, C23.2, C24.2, C29.2, C30.2, C35.2, C39.1, C42.2, C43.2, C45.1, C46.1, C47.1, C52.2, C53.2, C54.2, C55.2, C56.2, C57.2, C58.2, C59.2, C60.2, C61.2, C66.2, C67.2, C68.2, C69.2, C70.2, C71.2, C72.2, C73.2, C74.2, C75.2, C76.2, C77.2, C78.2, C79.2, C80.2, C81.2, C82.2, C83.2, C84.2, C85.2, C86.2, C87.2, D1.1 (A1), D2.1 (A1), D3.1 (A1), D4.1 (A1), D33.1 (A1), D34.1 (A1), D35.1 (A1), D36.1 (A1), D37.1 (A1), D38.1 (A1), D39.1 (A1), D40.1 (A1), D41.1 (A1), D42.1 (A1), D43.1 (A1), D44.1 (A1), D45.1 (A1), D46.1 (A1), D47.1 (A1), D48.1 (A1), D49.1 (A1), D50.1 (A1), D51.1 (A1), D52.1 (A1), GND.1, J1.1, J2.1, J3.1, J4.1, J5.1, J11.A1 (GND), J11.A12 (GND), J11.B1 (GND), J11.B12 (GND), J11.SH (SHIELD), J16.1, J52.1, J53.1, J54.1, J55.1, J56.1, J57.1, J58.1, J59.1, J60.1, J61.1, J62.1, J63.1, J64.1, J65.1, J66.1, J67.1, R12.1, R14.1, R21.2, R22.1, R23.1, R29.1, R30.1, R41.1, R46.1, R47.1, R52.2, R53.2, R81.1, R85.1, R87.1, R89.1, R94.1, R94.2, R99.1, R101.1, R103.1, R105.1, R107.1, R109.1, R111.1, R113.1, R115.1, R117.1, R119.1, R121.1, U1.11 (V-), U2.3 (AGND), U2.9 (PGND1), U2.11 (PGND2), U4.6 (AGND), U4.12 (PGND), U4.15 (EP), U4.21 (EP), U4.GND, U5.6 (AGND), U5.12 (PGND), U5.15 (EP), U5.21 (EP), U5.GND, U8.1 (Source), U10.1 (Source), U11.2 (GND), U14.16 (VSS), U14.31 (VSSA), U14.38 (VSS), U14.51 (VSS), U14.61 (VSS), U14.83 (VSS), U14.94 (VSS), U14.107 (VSS), U14.120 (VSS), U14.130 (VSS), U16.1 (Source), U17.1 (Source), U18.1 (Source), U19.1 (Source), U20.1 (Source), U21.1 (Source), U22.1 (Source), U23.1 (Source), U24.1 (Source), U25.1 (Source), U26.1 (Source), U27.1 (Source), U28.1 (Source), U29.1 (Source), U30.11 (V-), U31.11 (V-), U32.11 (V-), U33.11 (V-), U34.1 (Source), U35.1 (Source)
Heater1: R84.1, U14.70 (PB11)
Heater2: R86.1, U14.69 (PB10)
Heater3: R80.1, U14.36 (PA2)
Heater4: R88.1, U14.35 (PA1)
unnamed: C5.1, R6.1
unnamed: C24.1, R5.2
unnamed: C31.2, R44.2
unnamed: C32.2, R45.2
unnamed: C40.1, R60.1
unnamed: C41.1, R61.1
unnamed: 12V.1, C42.1, F2.2, L4.2, R54.2, R60.2
unnamed: C43.1, F3.2, L5.2, R55.2, R61.2
unnamed: C44.1, R30.2, SW1.1
unnamed: C6.1, D1.2 (A2), J2.2, R1.1, R7.2
unnamed: C7.1, D2.2 (A2), J3.2, R2.1, R8.2
unnamed: C8.1, D3.2 (A2), J4.2, R3.1, R9.2
unnamed: C9.1, D4.2 (A2), J5.2, R4.1, R10.2
unnamed: D21.1 (A1), J29.2, U18.3 (Drain)
unnamed: D21.2 (A2), J28.2, J28.4, J28.6, J29.1
unnamed: D22.1 (A1), J31.2, U19.3 (Drain)
unnamed: D22.2 (A2), J30.2, J30.4, J30.6, J31.1
unnamed: D23.1 (A1), J33.2, U20.3 (Drain)
unnamed: D23.2 (A2), J32.2, J32.4, J32.6, J33.1
unnamed: D24.1 (A1), J35.2, U21.3 (Drain)
unnamed: D24.2 (A2), J34.2, J34.4, J34.6, J35.1
unnamed: D25.1 (A1), J37.2, U22.3 (Drain)
unnamed: D25.2 (A2), J36.2, J36.4, J36.6, J37.1
unnamed: D26.1 (A1), J39.2, U23.3 (Drain)
unnamed: D26.2 (A2), J38.2, J38.4, J38.6, J39.1
unnamed: D27.1 (A1), J41.2, U24.3 (Drain)
unnamed: D27.2 (A2), J40.2, J40.4, J40.6, J41.1
unnamed: D28.1 (A1), J43.2, U25.3 (Drain)
unnamed: D28.2 (A2), J42.2, J42.4, J42.6, J43.1
unnamed: D29.1 (A1), J45.2, U26.3 (Drain)
unnamed: D29.2 (A2), J44.2, J44.4, J44.6, J45.1
unnamed: D30.1 (A1), J47.2, U27.3 (Drain)
unnamed: D30.2 (A2), J46.2, J46.4, J46.6, J47.1
unnamed: D31.1 (A1), J49.2, U28.3 (Drain)
unnamed: D31.2 (A2), J48.2, J48.4, J48.6, J49.1
unnamed: D32.1 (A1), J51.2, U29.3 (Drain)
unnamed: D32.2 (A2), J50.2, J50.4, J50.6, J51.1
unnamed: C72.1, D33.2 (A2), J52.2, R122.1, R124.2
unnamed: C73.1, D34.2 (A2), J53.2, R123.1, R125.2
unnamed: C74.1, D35.2 (A2), J54.2, R128.1, R130.2
unnamed: C75.1, D36.2 (A2), J55.2, R129.1, R131.2
unnamed: C76.1, D37.2 (A2), J56.2, R134.1, R136.2
unnamed: C77.1, D38.2 (A2), J57.2, R135.1, R137.2
unnamed: C78.1, D39.2 (A2), J58.2, R140.1, R142.2
unnamed: C79.1, D40.2 (A2), J59.2, R141.1, R143.2
unnamed: C80.1, D41.2 (A2), J60.2, R146.1, R148.2
unnamed: C81.1, D42.2 (A2), J61.2, R147.1, R149.2
unnamed: C82.1, D43.2 (A2), J62.2, R152.1, R154.2
unnamed: C83.1, D44.2 (A2), J63.2, R153.1, R155.2
unnamed: C84.1, D45.2 (A2), J64.2, R158.1, R160.2
unnamed: C85.1, D46.2 (A2), J65.2, R159.1, R161.2
unnamed: C86.1, D47.2 (A2), J66.2, R164.1, R166.2
unnamed: C87.1, D48.2 (A2), J67.2, R165.1, R167.2
unnamed: D49.2 (A2), J26.2, R90.1, R90.2, U16.3 (Drain)
unnamed: D50.2 (A2), J68.2, R91.1, R91.2, U34.3 (Drain)
unnamed: D51.2 (A2), J69.2, R92.1, R92.2, U35.3 (Drain)
unnamed: D52.2 (A2), J27.2, R93.1, R93.2, U17.3 (Drain)
unnamed: F1.2, J1.2
unnamed: C3.1, C10.1, C13.1, C14.1, J6.2, U2.7 (EN_SYNC), U2.8 (VIN1), U2.12 (VIN2)
unnamed: J11.A5 (CC1), R52.1
unnamed: J11.B5 (CC2), R53.1
unnamed: J11.A6 (D+), J11.B6 (D+), U11.1 (I/O1)
unnamed: J11.A7 (D-), J11.B7 (D-), U11.3 (I/O2)
unnamed: F4.2, J16.2
unnamed: R28.2, SW2.1
unnamed: R7.1, U1.3 (+)
unnamed: R15.2, U1.1, U1.2 (-)
unnamed: R8.1, U1.5 (+)
unnamed: R16.2, U1.6 (-), U1.7
unnamed: R10.1, U1.10 (+)
unnamed: R18.2, U1.8, U1.9 (-)
unnamed: R9.1, U1.12 (+)
unnamed: R17.2, U1.13 (-), U1.14
unnamed: C26.1, U2.13 (RBOOT), U2.14 (CBOOT)
unnamed: R40.1, R41.2, U2.4 (FB)
unnamed: R21.1, U2.5 (PGOOD)
unnamed: C26.2, L3.1, U2.10 (SW)
unnamed: C17.1, U2.2 (VCC)
unnamed: C27.1, U4.17 (BST)
unnamed: C31.1, C33.1, U4.4 (COMP)
unnamed: R11.1, R12.2, U4.1 (EN_UVLO)
unnamed: C33.2, C40.2, R44.1, R46.2, R54.1, U4.5 (FB)
unnamed: U4.18 (HO), U7.2 (Gate)
unnamed: C29.1, R42.2, U4.11 (ILIM)
unnamed: U4.13 (LO), U8.2 (Gate)
unnamed: R25.1, U4.10 (PGOOD)
unnamed: R22.2, U4.2 (RT)
unnamed: C18.1, U4.3 (SS_TRK)
unnamed: C27.2, L4.1, R42.1, U4.19 (SW), U7.1 (Source), U8.3 (Drain)
unnamed: R24.1, U4.8 (SYNCIN)
unnamed: C20.1, R24.2, R25.2, U4.14 (VCC)
unnamed: C15.1, R19.1, U4.20 (VIN)
unnamed: C28.1, U5.17 (BST)
unnamed: C32.1, C34.1, U5.4 (COMP)
unnamed: R13.1, R14.2, U5.1 (EN_UVLO)
unnamed: C34.2, C41.2, R45.1, R47.2, R55.1, U5.5 (FB)
unnamed: U5.18 (HO), U9.2 (Gate)
unnamed: C30.1, R43.2, U5.11 (ILIM)
unnamed: R27.1, U5.10 (PGOOD)
unnamed: R23.2, U5.2 (RT)
unnamed: C19.1, U5.3 (SS_TRK)
unnamed: R26.1, U5.8 (SYNCIN)
unnamed: C21.1, R26.2, R27.2, U5.14 (VCC)
unnamed: C16.1, R20.1, U5.20 (VIN)
unnamed: C11.1, L1.2, R5.1, R11.2, R19.2, U7.3 (Drain)
unnamed: C12.1, L2.2, R6.2, R13.2, R20.2, U9.3 (Drain)
unnamed: C28.2, L5.1, R43.1, U5.19 (SW), U9.1 (Source), U10.3 (Drain)
unnamed: U5.13 (LO), U10.2 (Gate)
unnamed: C44.2, SW1.2, U14.25 (NRST)
unnamed: R82.1, U14.103 (PA11)
unnamed: R83.1, U14.104 (PA12)
unnamed: C46.2, U14.71 (VCAP_1)
unnamed: C47.2, U14.106 (VCAP_2)
unnamed: C45.2, U14.32 (VREF+)
unnamed: R80.2, R81.2, U16.2 (Gate)
unnamed: R88.2, R89.2, U17.2 (Gate)
unnamed: R98.2, R99.2, U18.2 (Gate)
unnamed: R100.2, R101.2, U19.2 (Gate)
unnamed: R102.2, R103.2, U20.2 (Gate)
unnamed: R104.2, R105.2, U21.2 (Gate)
unnamed: R106.2, R107.2, U22.2 (Gate)
unnamed: R108.2, R109.2, U23.2 (Gate)
unnamed: R110.2, R111.2, U24.2 (Gate)
unnamed: R112.2, R113.2, U25.2 (Gate)
unnamed: R114.2, R115.2, U26.2 (Gate)
unnamed: R116.2, R117.2, U27.2 (Gate)
unnamed: R118.2, R119.2, U28.2 (Gate)
unnamed: R120.2, R121.2, U29.2 (Gate)
unnamed: R124.1, U30.3 (+)
unnamed: R126.2, U30.1, U30.2 (-)
unnamed: R125.1, U30.5 (+)
unnamed: R127.2, U30.6 (-), U30.7
unnamed: R131.1, U30.10 (+)
unnamed: R133.2, U30.8, U30.9 (-)
unnamed: R130.1, U30.12 (+)
unnamed: R132.2, U30.13 (-), U30.14
unnamed: R136.1, U31.3 (+)
unnamed: R138.2, U31.1, U31.2 (-)
unnamed: R137.1, U31.5 (+)
unnamed: R139.2, U31.6 (-), U31.7
unnamed: R143.1, U31.10 (+)
unnamed: R145.2, U31.8, U31.9 (-)
unnamed: R142.1, U31.12 (+)
unnamed: R144.2, U31.13 (-), U31.14
unnamed: R148.1, U32.3 (+)
unnamed: R150.2, U32.1, U32.2 (-)
unnamed: R149.1, U32.5 (+)
unnamed: R151.2, U32.6 (-), U32.7
unnamed: R155.1, U32.10 (+)
unnamed: R157.2, U32.8, U32.9 (-)
unnamed: R154.1, U32.12 (+)
unnamed: R156.2, U32.13 (-), U32.14
unnamed: R160.1, U33.3 (+)
unnamed: R162.2, U33.1, U33.2 (-)
unnamed: R161.1, U33.5 (+)
unnamed: R163.2, U33.6 (-), U33.7
unnamed: R167.1, U33.10 (+)
unnamed: R169.2, U33.8, U33.9 (-)
unnamed: R166.1, U33.12 (+)
unnamed: R168.2, U33.13 (-), U33.14
unnamed: R84.2, R85.2, U34.2 (Gate)
unnamed: R86.2, R87.2, U35.2 (Gate)
Thermistor1: R15.1, U14.40 (PA4)
Thermistor2: R16.1, U14.45 (PC5)
Thermistor3: R17.1, U14.41 (PA5)
Thermistor4: R18.1, U14.46 (PB0)
Thermistor5: R126.1, U14.47 (PB1)
Thermistor6: R127.1, U14.43 (PA7)
Thermistor7: R132.1, U14.44 (PC4)
Thermistor8: R133.1, U14.42 (PA6)
Thermistor9: R138.1, U14.26 (PC0)
Thermistor10: R139.1, U14.27 (PC1)
Thermistor11: R144.1, U14.28 (PC2)
Thermistor12: R145.1, U14.29 (PC3)
Thermistor13: R150.1, U14.13 (PF3)
Thermistor14: R151.1, U14.18 (PF6)
Thermistor15: R156.1, U14.14 (PF4)
Thermistor16: R157.1, U14.15 (PF5)
Thermistor17: R162.1, U14.20 (PF8)
Thermistor18: R163.1, U14.19 (PF7)
Thermistor19: R168.1, U14.22 (PF10)
Thermistor20: R169.1, U14.21 (PF9)
USB5V: C39.2, J6.1, J11.A4 (VBUS), J11.A9 (VBUS), J11.B4 (VBUS), J11.B9 (VBUS), U11.5 (VBUS)
USB_D+: R83.2, U11.6 (I/O1)
USB_D-: R82.2, U11.4 (I/O2)
VBUS: C2.1, C4.1, C22.1, C23.1, F1.1, J6.3, J28.1, J30.1, J32.1, J34.1, J36.1, J38.1, J40.1, J42.1, J44.1, J46.1, J48.1, J50.1, L1.1, L2.1, VBUS.1
VHeaters: F4.1, J26.1, J27.1, J68.1, J69.1

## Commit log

2026-06-07 Add initial project journal for Klipper board modification
    Document initial project setup and requirements for modifying a Klipper board, including MCU selection and thermistor input specifications.
2026-06-11 Update journal with fan circuit design progress
    Documented progress on fan circuit design, including overcurrent protection decisions, MOSFET selection, and thermistor integration. Updated task list and overall schematic.
2026-06-17 did some stuff
    [12V_Buck_Conv.kicad_sch, 3V3_Buck_Conv.kicad_sch, 4Thermistors.kicad_sch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]
2026-06-20 did stuff
    [12V_Buck_Conv.kicad_sch, 3V3_Buck_Conv.kicad_sch, 4Thermistors.kicad_sch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]
2026-06-22 did stuff (uploading kicad bits)
    [Fan controller.kicad_sch, brewery 3dp motherboard.kicad_pcb]
2026-06-25 Update journal with BOM component selection details
    Documented the process of selecting components for the BOM, including considerations for voltage ratings and component availability.
2026-06-25 Enhance README with features and specifications
    Added detailed features and specifications for the 3D printer expansion board, including thermistor and fan outputs, power management, and temperature monitoring capabilities.
2026-06-25 cleaned up structure a bit
    [12V_Buck_Conv.kicad_sch, 3V3_Buck_Conv.kicad_sch, 4Thermistors.kicad_sch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]
2026-06-29 Add BOM section with cost breakdown in README
    Added a Bill of Materials (BOM) section with cost details.
2026-09-26 Update journal with PCB assembly and troubleshooting details
    Documented the assembly and troubleshooting process of the PCB build, including component sorting, soldering issues, and debugging steps taken to resolve voltage problems and communication with the STM32.
